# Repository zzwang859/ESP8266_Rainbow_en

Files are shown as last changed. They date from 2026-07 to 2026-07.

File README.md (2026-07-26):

# Rainbow ESP8266

## Features

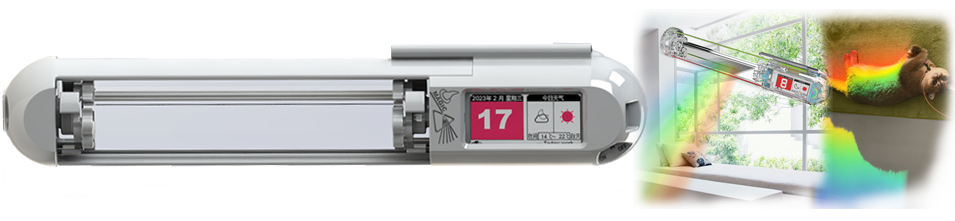
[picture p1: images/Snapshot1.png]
Toy Snapshot


This is an ESP8266-based toy developed with the Arduino environment. It accurately calculates the position of the sun based on geographic location and time, then adjusts the prism's orientation in real time to disperse sunlight into a rainbow projected inside the room, creating a calm and pleasant atmosphere. The program includes a low-power sleep mechanism that allows it to run entirely on solar power. It can also connect to WiFi to retrieve information and display the date, weather, battery level, and configuration status on an e-paper screen.  
[Visit here for more information and a demonstration](https://www.bilibili.com/video/BV1gX4y1D7wM/?vd_source=42ecb46c8304961543d4f286cf99d5a6)

[需要中文版本资料，请点击这里访问中文仓库](https://github.com/zzwang859/ESP8266_Rainbow_zh)

## Directory Structure
```text
.
├── Rainbowv1.0_ESP8266.ino      # Arduino main program entry point
├── Libraries/                   # Archived third-party library packages
│   ├── ArduinoJson.rar
│   ├── ESP8266-Seniverse-master.zip
│   └── NTPClient.rar
├── src/                         # Project source modules
│   ├── config.h                 # Top-level feature configuration macros
│   ├── app_types.h              # Global data structures and state enumerations
│   ├── adc/                     # ADC, battery voltage, and infrared sensor sampling
│   ├── DS1302/                  # DS1302 clock chip driver
│   ├── Epaper/                  # E-paper driver, UI refresh, and image resources
│   ├── moto/                    # Stepper motor control and prism position calibration
│   ├── Sun/                     # Solar position calculation and optimal prism angle search
│   └── wifi_html/               # HTML resources for the WiFi configuration page
├── docments/                    # Project documentation/resources, including program flowcharts and finished product manual
├── Print_Step/                   # Enclosure source files for 3D printing
├── PCB_SCH/                     # Schematic and PCB files
└── images/                      # Finished product photos and actual effect images
```

## Code Deployment Instructions

### Main Program
`Rainbowv1.0_ESP8266.ino` is the main entry point of the Arduino sketch. It contains `setup()`, `loop()`, and the project-level state machine logic. It coordinates the following processes:

- Determine the reset source after power-on/deep-sleep wake-up.
- Restore configuration and operating state from Flash or RTC memory.
- WiFi Station/SoftAP configuration process.
- Time synchronization among NTP, DS1302, and the local perpetual calendar.
- Retrieve weather data and select the city ID.
- Calculate the solar position, sunlight period, and optimal prism angle.
- Schedule stepper motor operations.
- Refresh e-paper display pages.
- Detect low battery and enter low-power sleep.

### Configuration and Global Types
#### `src/config.h`
This is the top-level configuration entry point for the project. The main macros include:  
- `OFFLINE_TEST`: Enables or disables offline/development test mode.
- `DEBUG_INFO_EN`: Enables or disables debug information output.
- `USE_EINK_SCREEN`: Determines whether the e-paper screen is enabled.
- `BAT_LOW_GATE`: Low-battery protection threshold.
- `EINK_MODEL`: E-paper hardware model.
- `EINK_UI_LANGUAGE`: UI language selection, configurable as Chinese or English.

*To customize the startup image, modify the array data of img_config_red &img_config_black in src/epaper/epaper_bmp.h*

### Third-Party Dependencies
The project uses the following Arduino/ESP8266 libraries:
- Libraries included with ESP8266 Arduino Core: `ESP8266WiFi`, `DNSServer`, `ESP8266WebServer`, `SPI`, and `WiFiUdp`.

Third-party library packages are stored in the `Libraries/` directory. Before compilation, make sure these libraries are correctly installed in the Arduino IDE or located in a path that the compiler can search,  
usually: `\Users\name\Documents\Arduino\libraries\ `<br>
- `ArduinoJson`
- `ESP8266_Seniverse`
- `NTPClient`

### Code Maintenance
- Modify top-level feature switches in `src/config.h` first.
- Refer to `src/app_types.h` first for global state structures.
- Hardware pin-related macros are located in the header files of their corresponding modules.

## Schematic and PCB 

The schematic and PCB files are located in `PCB_SCH/` and were designed using EasyEDA. After obtaining them, you will need to manufacture the circuit board yourself. Fortunately, only a small number of inexpensive components are required. All components use 0603 packages, so there are no demanding requirements for soldering equipment or skills. If you are in China, you can have the circuit board manufactured for free by JLCPCB.

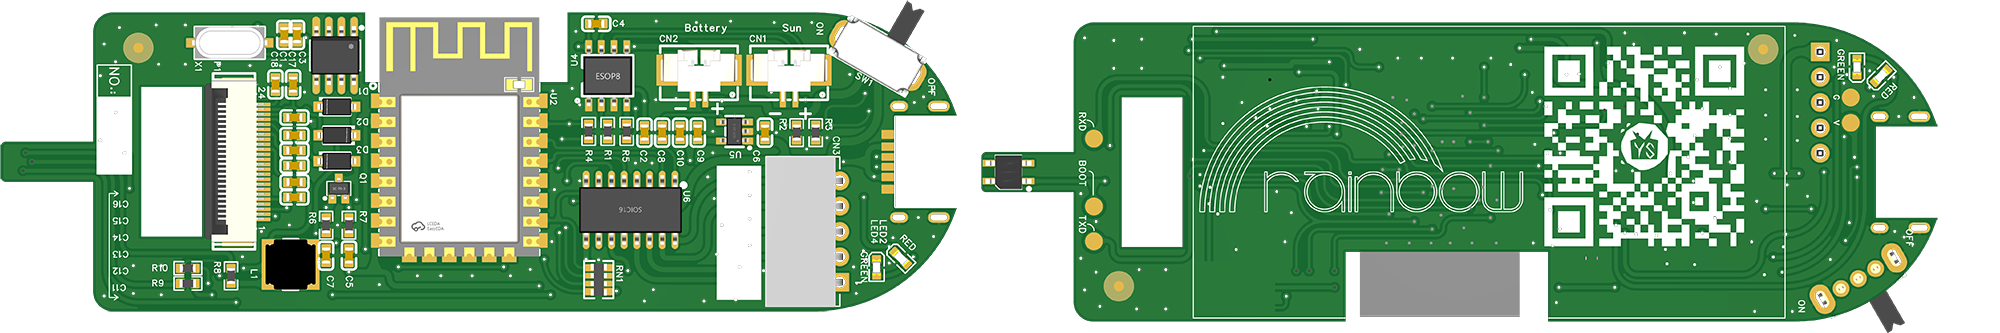
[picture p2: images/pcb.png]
PCBA


## Enclosure and Bill of Materials
The 3D-printable enclosure files are located in the `Print_Step` directory. However, additional materials, such as stepper motors and a solar panel, are required to assemble the complete product. The list is as follows:

|Part Name| Quantity|Unit|Specifications|Notes|
|:---:|:---:|:---:|:---:|:---:|
| Enclosure| 2 |sets | PLA/PETG | 3D Printed |
| PCB| 1 |piece | Fully assembled | DIY |
| Triangular Prism| 1 |piece | 30*30*150mm | Buy |
| Solar Panel| 1|piece |90*30mm 5.5V |Buy|
| Stepper Motor| 2|pieces|28BYJ-48 DC5V | Buy|
| Battery| 2|pieces|102540 1100mAh 1.25mm*2Pin|Buy|
| Bearing| 2|pieces|10mm inner diameter, 22mm outer diameter, 8mm thickness|Buy|
| Brass Standoff| 2|pieces|M3*18mm |Buy|
| E-paper Display|1|piece| 2.13" |Buy|
| M3 Bolt|4 |pieces|M3*10mm |Buy|
| M6 Bolt|2 |pieces|M6*20mm hex socket |Buy|
| M6 Nut|2 |pieces|M6 |Buy|
| M6 Washer|2 |pieces|M6*12*1mm |Buy|

## Finished Product Installation and Setup

#### Mounting on Window Glass
1. First, determine the installation location. This toy requires a vertical window exposed to sunlight. (Horizontal skylights or sloped attic windows are not suitable for installing this toy.)
2. Be sure to clean the glass first to prevent dust or dirt from weakening the adhesive hooks.
3. Attach the adhesive hooks to the product first to ensure the spacing between the hooks is correct.
4. Peel off the backing from the hooks, press the product firmly onto the glass, and ensure that it adheres securely.
5. Remove the product from the hooks, press the hooks firmly against the glass again, and then hang the product back in place.

#### Placing on a Windowsill with Stands
The 3D printing files are located in the `Print_Step` directory, which includes files for a pair of stands that can be printed to support the device.

### Initial Setup

1. Turn on the product's power switch. Use a phone or computer to find and connect to the hotspot named rainbow. The password is 12345678.
2. Then open 192.168.4.1 in a mobile browser. The interface is shown below. Follow the on-screen instructions to enter your home WIFI name and password, the longitude, latitude, and altitude of the installation location, and the window orientation. Then click Connect.<br>

<p align="center">
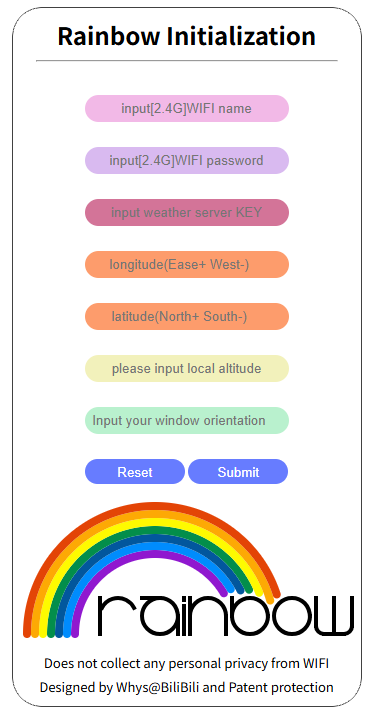
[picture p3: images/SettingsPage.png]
Setting page
  
</p><br>

+ The target WIFI network supports only 2.4 GHz. Connecting to a 5 GHz WIFI hotspot will fail. When configuring with a mobile hotspot, enable the "Maximize Compatibility" option.
+ Verify that the WIFI password is correct. Public WIFI and other hotspots that require additional authentication after connection to access the Internet are not suitable for this toy.
+ For the weather private key, enter "OFF" if you do not use the weather forecast feature. In mainland China, Seniverse is used as the third-party weather information service provider, and users can register a free account with a personal mobile phone number to obtain a private key. If the program is compiled in English, the weather forecast source is Caiyun Weather, which requires a paid subscription.

3. Longitude and latitude data must be entered in decimal format with 5–6 decimal places to provide an accurate geographic location. A more convenient method is to look up the longitude and latitude online at <https://api.map.baidu.com/lbsapi/getpoint/index.html>.<br>
If the data is in degrees-minutes-seconds format (for example, 30°20'56"), convert it to decimal format using the following formula:<br>
$$
\text{Decimal Degrees}
=
\text{Degrees}
+
\frac{\text{Minutes}}{60}
+
\frac{\text{Seconds}}{3600}
$$<br>

4. Altitude can be obtained from a map app or a third-party compass app. The altitude does not need to be precise; an error of about 100 meters has virtually no effect.
- Optional hidden settings can be appended to the altitude value for users with special application requirements. The format and descriptions of the additional settings are shown below. Square brackets around optional parameters are required, and the letters in `UTC/ADJ/NTP/LPR` are case-sensitive.  
    **Required Parameter**<br>
    - Altitude value (required)

    **Optional Parameters**<br>
    - Custom time zone, such as `[UTC+8] 、[UTC-5]` <br>
    - Coordinate system fine-tuning. To compensate for stepper motor gear error, a coordinate system adjustment setting is provided. To make the rainbow smaller and brighter (with a more concentrated beam), adjust slightly in the negative direction, for example: `[ADJ-3.0]`; to make the rainbow larger (more dispersed), adjust slightly in the positive direction, for example: `[ADJ3.0]`. The adjustment is generally within ±6 degrees. Excessive adjustment may prevent a rainbow from forming. <br>
    - Custom NTP time server, for example `[NTPntp1.aliyun.com]` <br>
    
    ```bash
    w32tm /stripchart /computer:ntp.tencent.com  # Method for checking whether an NTP server is available on Windows
    ```
    Some commonly used NTP servers are listed below:
    ```text
    ntp1.aliyun.com
    pool.ntp.org
    ntp.tencent.com
    time.cloud.tencent.com
    time.apple.com
    time.google.com (unavailable in mainland China)
    time.facebook.com (unavailable in mainland China)
    ntp.ix.ru (Moscow)
    ntp.jst.mfeed.ad.jp (Japan)
    ```

    - Custom low-battery warning voltage, for example `[LPR750]`. The valid range is 0–1024. Because the ESP8266 ADC readings are inaccurate, this parameter is provided to prevent the device from incorrectly entering low-battery sleep too early. Setting it to 0 effectively disables low-battery sleep.

5. Window orientation
      The window orientation is a numeric value. True north is 0, and the north-east-south-west-north sequence corresponds to 0–360 degrees, as shown below. Point your phone's built-in compass app toward the window; the displayed reading is the window orientation value.
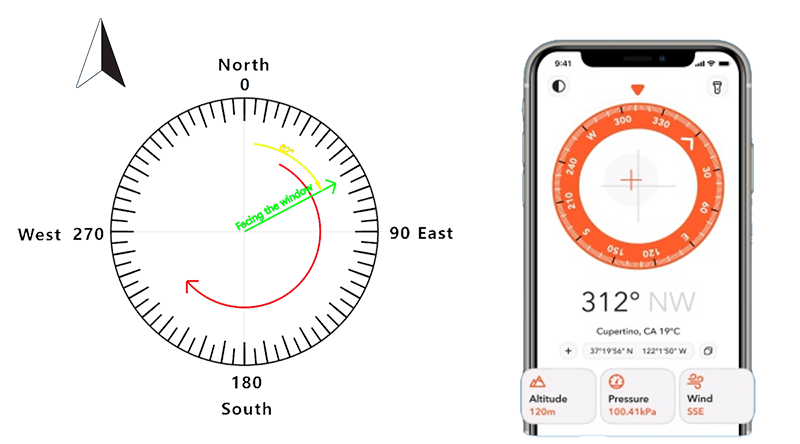
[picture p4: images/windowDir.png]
windowDir
      

*The longitude, latitude, altitude, and window orientation parameters can all be obtained from the phone's built-in "Compass" app. When taking measurements, place the phone flat and point it directly toward the window. (Since iOS 14, Apple's built-in "Compass" app no longer displays longitude, latitude, and altitude information. You can download a third-party "Compass" app from the App Store to obtain this information.)*

#### E-paper Display Information
<p align="center">
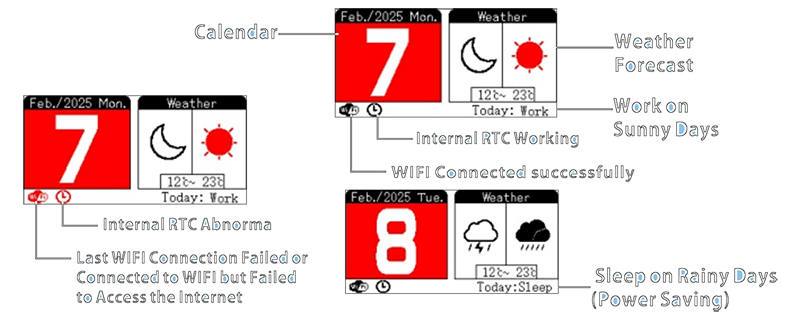
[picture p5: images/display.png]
Display]
  
</p><br>

## ⚠️ Safety Precautions
* Before mounting the product on indoor glass, clean the glass thoroughly to prevent dust or grease from weakening the adhesive bond. 
* Do not manually rotate the product using external force, as this may break the internal gears and damage the product. 
* Do not install the product outdoors on a high-rise building, as an accidental fall could cause personal injury. 
* When the battery is depleted, charge it using a Type-C USB cable. 
* This product is not suitable for use or play by children under 9 years old. 
* This product does not concentrate light and therefore does not present a fire hazard from concentrated sunlight.

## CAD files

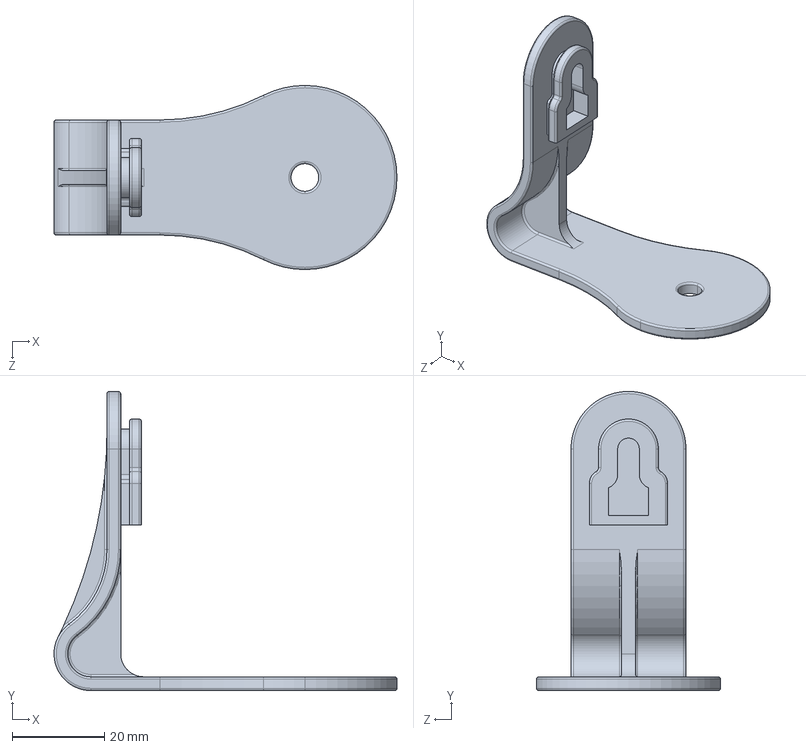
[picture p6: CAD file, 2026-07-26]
Print_Step/bracketx2.STEP
74.5 x 65.0 x 40.0 mm

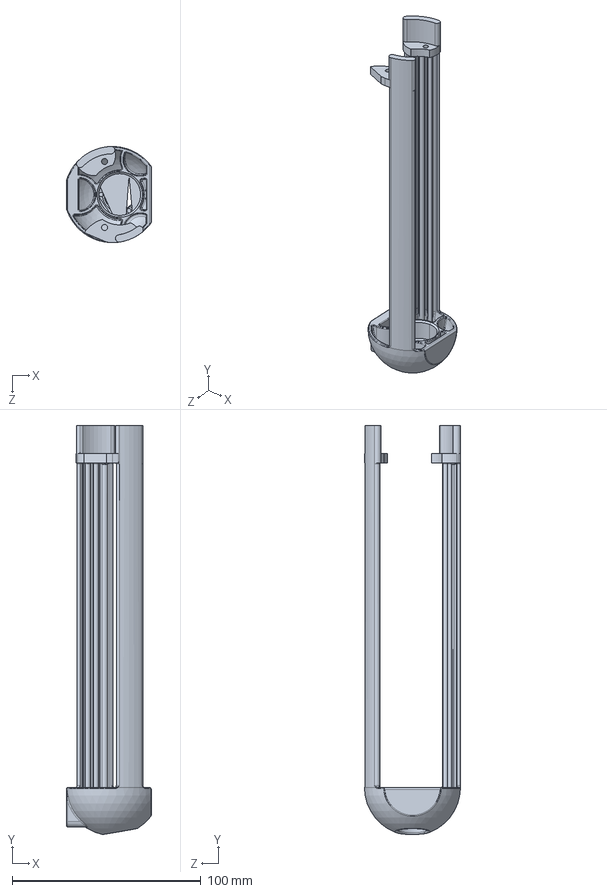
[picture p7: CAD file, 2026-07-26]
Print_Step/L_casing.STEP
44.8 x 216.8 x 51.0 mm

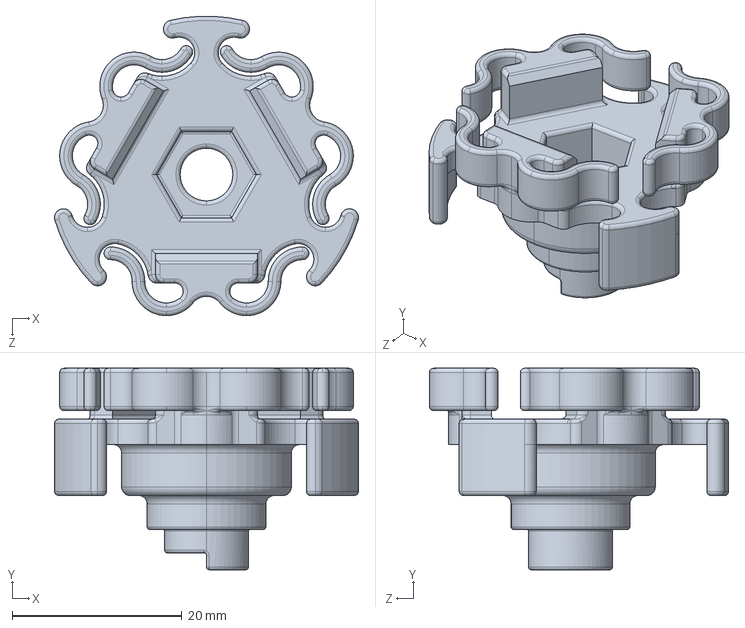
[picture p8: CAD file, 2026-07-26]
Print_Step/Prism_clipR.STEP
35.8 x 23.8 x 35.3 mm

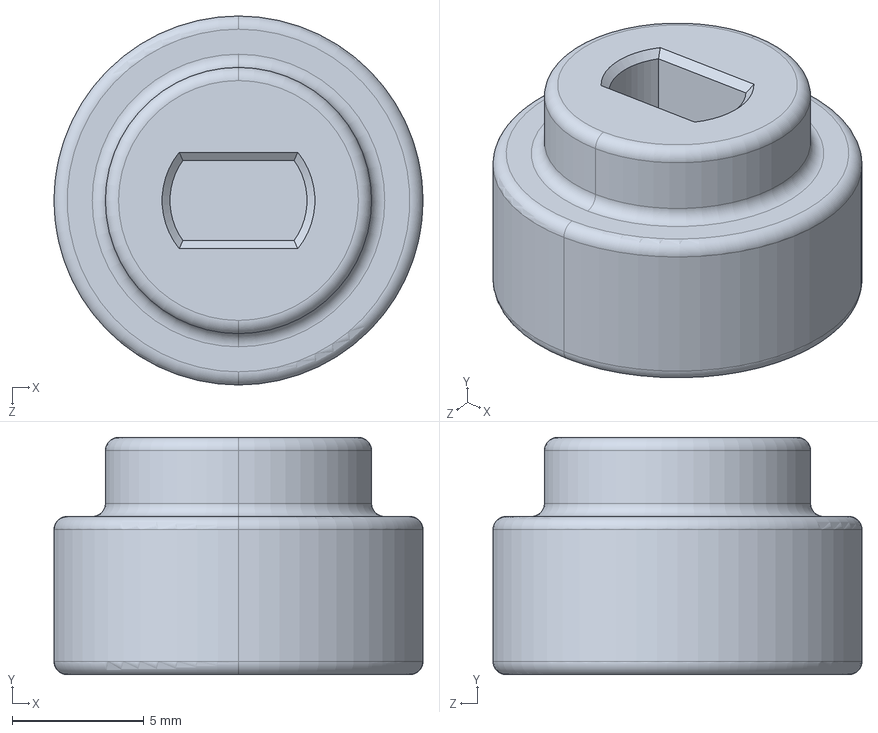
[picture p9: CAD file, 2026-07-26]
Print_Step/Shaft_coupling.STEP
14.0 x 9.00 x 14.0 mm

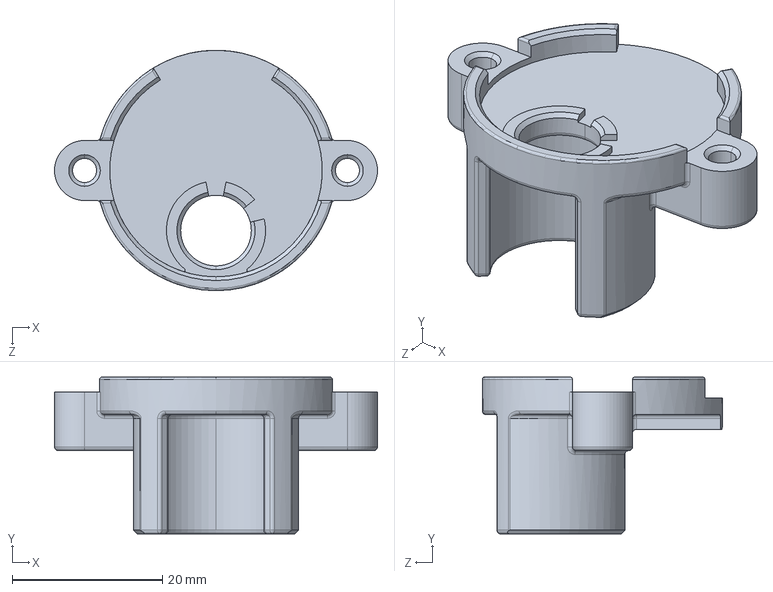
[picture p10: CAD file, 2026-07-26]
Print_Step/motor_base.STEP
43.0 x 20.9 x 32.0 mm

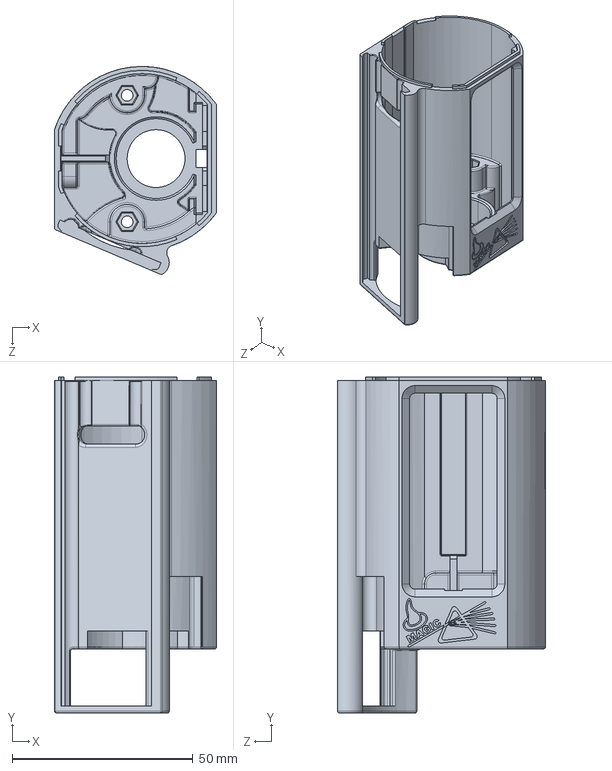
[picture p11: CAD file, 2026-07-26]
Print_Step/R_casing.STEP
44.8 x 93.0 x 57.6 mm

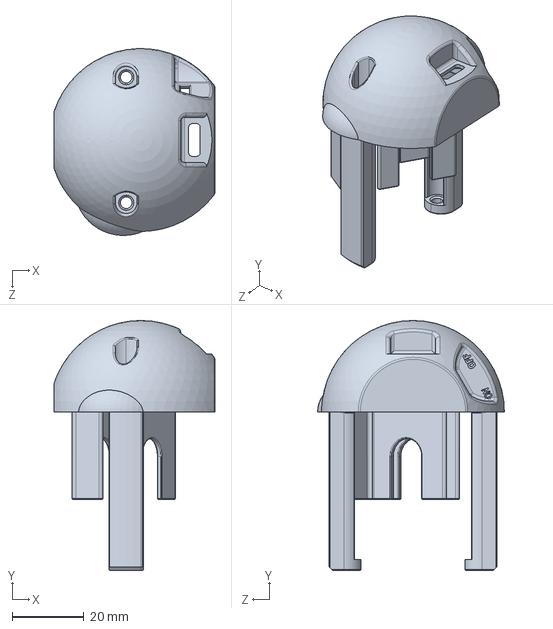
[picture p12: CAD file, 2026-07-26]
Print_Step/end_cover.STEP
44.8 x 69.7 x 52.1 mm

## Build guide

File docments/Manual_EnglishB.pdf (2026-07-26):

2

## installation method

## Initial Setup

## Precautions

When attaching to indoor glass, please clean the glass in advance to avoid dust or oil stains that may cause the adhesive to fail.
Do not manually rotate the product with external force, as this may cause internal gears to break and damage the product.
Do not install the product outdoors at high levels to prevent accidental falls that could cause injury to others.
When the battery is depleted, please use a Type-C USB cable to charge .

This product does not have the function of focusing light and will not cause fire hazards due to sunlight concentration and temperature rise.

This product is not suitable for use or play by children under 9 years old.

Step One: First, determine the installation location. This toy requires a vertical window that can be exposed to sunlight (horizontal skylights or attic windows with an incline are not suitable for installing this toy).

80.356481[UTC-5][ADJ3.0][NTPtime.google.com]

Turn on the power switch of the product, use your phone or computer to find a hotspot named "rainbow" connect to this hotspot, and the password is 12345678

Then, using your phone's browser, open the URL 192.168.4.1 The interface will appear as shown in the image below. Follow the on-screen instructions to fill in your home Wi-Fi's name and password, the latitude, longitude, and altitude of the installation location, and the orientation of the window. Click 'Connect' to proceed.

*If you need to change the parameters, toggle the power switch to turn off and then turn on the device again, and repeat the above steps

Step Three: First, attach the adhesive hooks to the product to ensure that the spacing between the hooks is appropriate.
Step Four: Peel off the adhesive backing from the hooks, then press the product firmly onto the glass to attach it.

Step Two: Be sure to wipe the glass clean first to prevent the adhesive hook from not sticking securely.

Step Five: Remove the product from the hooks, press the hooks further to ensure they are securely attached, and then hang the product back on the hooks.

## ParameterExplanationAnd Tips

1:The target Wi-Fi for connection only supports 2.4G; attempting to connect to a 5G Wi-Fi hotspot will fail. When setting up a mobile hotspot on your phone, please select the 'Best Compatibility' option."

1

Does not collect any personal privacy from WIFI Designed by Whys@BiliBili and Patent protection

input[2.4G]WIFIname

input[2.4G]WIFIpassword

inputweatherserverKEY

longitude(Ease+West-)

latitude(North+South-)

pleaseinputlocalaltitude

Inputyourwindoworientation

Reset | Submit

Rainbow Initialization

LoveHome

z77778888

OFF

-74.252564

40.670951

30

90

Reset | Submit
SetupInterface | FillingExample

2:Verify the Wi-Fi password to ensure it is correct. Public Wi-Fi hotspots that require additional verification to access the internet after connecting are not suitable for this toy. 3：weatherforecastsourceprivatekey
If you do not use the weather forecast feature, it can be set to 'OFF.' Weather is a third-party weather forecast information service provider. Users can register for a free account using their personal phone number to obtain a private key. A registration video tutorial is available; scan the QR code below to access and watch the instructions.
You can also leave it blank, in which case the built-in default private key will be used. However, this may result in weather forecast updates failing due to excessive usage by many users.

4：latitudeandlongitudedata
The format for entering latitude and longitude data should be in decimal format, with 5 to 6 decimal places to provide precise location information. If the data you find is in degrees-minutes-seconds (DMS) format, for example30°20'56".You can convert to decimal format using the formula: decimal format = D + M/60 + S/3600.
A more convenient way is to look up the latitude and longitude online. The QR code for the lookup link is provided below.

Facing the window

62°

GlassProduct

Recycling

CityCleanliness
Responsibility
PreventWater | DoNotStepOn

DoNotStepOn
WeatherAPIKeys | Latitude&LongitudeQuery

5：Altitude
You can check the altitude using a map APP or by installing a third-party compass APP. The altitude value does not need to be precise; an error of around a hundred meters will generally have no significant impact.

4

Hide Additional Parameters
After the altitude value, an Easter egg setting can be appended for users with special application needs to explore. Typically, there is no need to add this. The format and instructions for the additional settings are as follows:

AltitudeValue
(Required）

optionalparameters
CustomTimeZone

optionalparameters
Fine-tunethecoordinatesystem

*Bracketsarenecessaryinoptionalparameters，UTC/ADJ/NTParecase-sensitive

optionalparameters
CustomNTPtimeserver

Toaddressstepmotorgearerrors,asettinghasbeenaddedtoallowfine-tuningofthecoordinate system.
Tomaketherainbowsmallerandbrighter(morefocusedbeam),youcanslightlyadjustthecoordinates inthenegativedirection.Forexample,enter:80.35[ADJ-3.0] Tomaketherainbowarealarger(morespreadout),youcanslightlyadjustthecoordinatesinthe positivedirection.Forexample,enter:80.35[ADJ3.0] Generally,thefine-tuningangleshouldbewithin±6degrees.Over-adjustingmayresultintheinability

6：Window orientation
Window orientation is a pure numeric value, with true north being 0 degrees, and following the sequence of North-East-South-West-North, it corresponds to 0~360 degrees, as shown in the image below. You can use the reading from your phone's built-in compass APP when pointing it towards the window to get the window orientation value.

## 3 on-screen information

Weather
Forecast

Calendar

Workon
SunnyDays

SleeponRainyDays
(PowerSaving)

InternalRTCWorking

WIFI Connected successfully

InternalRTCAbnorma

LastWIFIConnectionFailedor ConnectedtoWIFIbutFailed toAccesstheInternet

CommunicationandQ&A

North

East

South

West

0

90

180

270

The latitude, longitude, altitude, and window orientation parameters can actually be obtained from the built-in 'Compass' app on your phone. When obtaining these values, please hold your phone flat and facing the window directly. (Note: The built-in 'Compass' app on Apple devices no longer displays latitude, longitude, and altitude information starting from iOS 14. You can download a third-party 'Compass' app from the App Store to get this information.)

Rainbow Initialization

180

Does not collect any personal privacy from WIFI Designed by Whys@BiliBili and Patent protection

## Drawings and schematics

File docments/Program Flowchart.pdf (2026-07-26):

## 复位运行

# 全局状

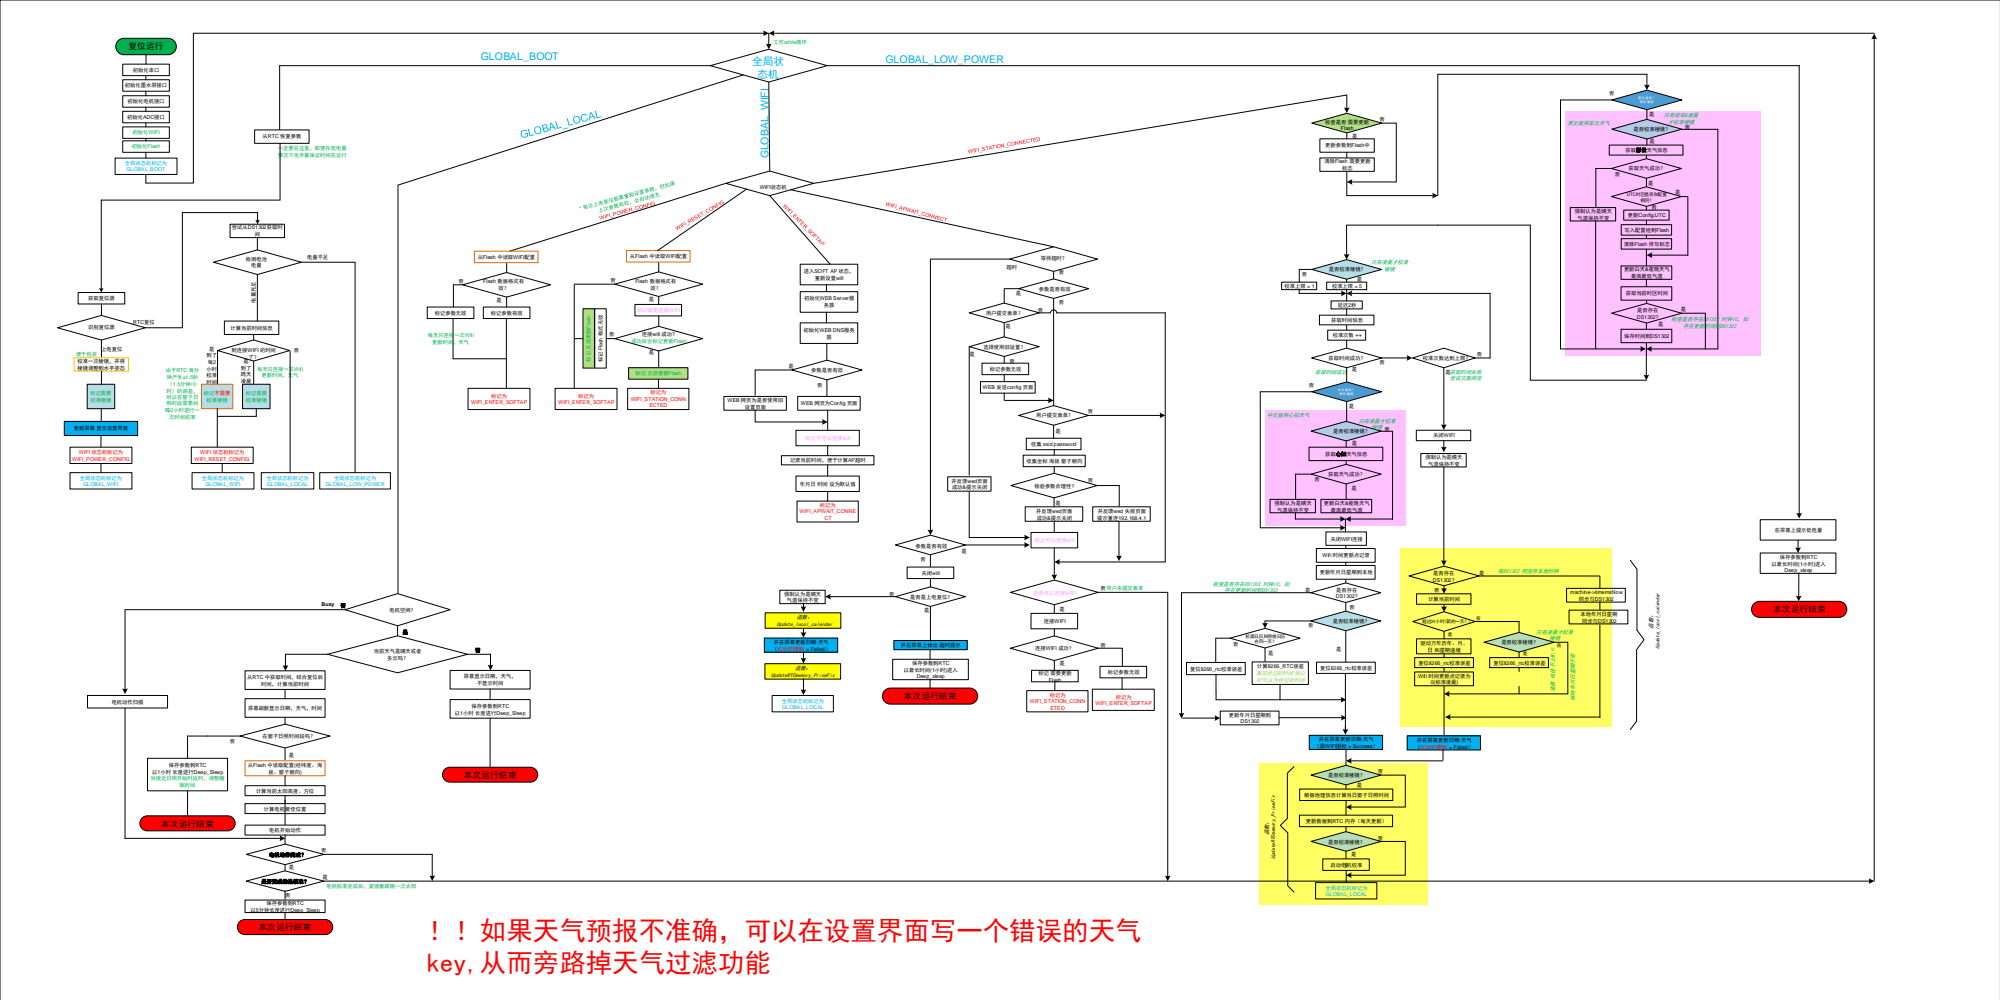
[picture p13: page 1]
初始化串口; 初始化墨水屏接口; 初始化电机接口; 初始化ADC接口; 初始化WIFI; 初始化Flash; 从Flash 中读取WIFI配置; Flash 数据格式有 效？; 连接WIFI; 连接WIFI 成功？; 标记为 WIFI_APWAIT_CONNE CT; 获取复位源; 识别复位源; 上电复位; RTC复位; WIFI状态机; 标记为 WIFI_STATION_CONN ECTED; 标记为 WIFI_ENTER_SOFTAP; 初始化WEB Server服 务器; 标记为 WIFI_STATION_CONN ETED; 标记 无须更新Flash; 标记 需要更新 Flash; 检查是否 需要更新 Flash; 更新参数到Flash中; 获取时间信息; 获取心知天气信息; 标记参数无效; 标记参数有效; 参数是否有效; WIFI 状态机标记为 WIFI_POWER_CONFIG; 全局状态机标记为 GLOBAL_WIFI; 计算当前时间信息; 到连接WIFI 的时间 了？; 每天只连接一次Wifi 更新时间，天气; 全局状态机标记为 GLOBAL_LOCAL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

进入SOFT AP 状态，
重新设置wifi

标记 Flash 格式无效

WEB 发送config 页面

WEB 网页为Config 页面 WEB 网页为是否使用旧

收集 ssid password

收集坐标 海拔 窗子朝向

年月日 时间 设为默认值

从RTC 中获取时间，结合复位后
时间，计算当前时间

屏幕刷新显示日期，天气，时间

从Flash 中读取配置(经纬度、海

更新数据到RTC 内存（每天更新）

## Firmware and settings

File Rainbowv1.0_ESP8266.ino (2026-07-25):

/*------------------------------------------------------------------------------------------------------------------------------------------------------------------------
*                                 Copyright (c) 2018, wangzz <-All rights reserved->
*               
**----------------------------------------------------------------------------------------------------------------------
*   File name:   rainbow.c
*   Brief description: Rainbow tracking clock main program
*
**----------------------------------------------------------------------------------------------------------------------
*   Current version:   V1.0
*   Author/modifier: whys
*   Completion date: November 8, 2022
**----------------------------------------------------------------------------------------------------------------------
*   Replacement version: 
*   Original author: 
*   Completion date: 
------------------------------------------------------------------------------------------------------------------------------------------------------------------------*/
#include <ESP8266WiFi.h>
#include <DNSServer.h>
#include <ESP8266WebServer.h>
#include <SPI.h>
#include <string.h>
#include <WiFiUdp.h>

#include <ArduinoJson.h>
#include <ESP8266_Seniverse.h>
#include <NTPClient.h>  /* NTP clock module */  

#include "src/config.h"                                     /* Project configuration macro                                 */
#include "src/app_types.h"                                  /* Global type and project configuration declarations                     */
#include "src/Sun/sun_position.h"                           /* Sun position calculation module declaration section                   */
#include "src/Sun/find_angle.h"                             /* Best pose finding algorithm declaration section                   */
#include "src/moto/moto.h"                                  /* Stepper motor driver declaration section                        */
#include "src/adc/adc.h"                                    /* ADC voltage acquisition statement section                       */
#include "src/DS1302/DS1302.h"                              /* DS1302 clock chip driver declaration part                */

/*------------------------------------------------------------------------------------------------------------------------------------------------------------------------
 * Statement related to WiFi configuration
------------------------------------------------------------------------------------------------------------------------------------------------------------------------*/
#define CONFIG_DATA_BASEADDR         0x100000          /* Store initial installation parameters at 1M location */
#define CONFIG_DATA_SECTOR           256               /* 1M position corresponds to 256 sectors  */
#define TIME_CORRECT_PERIOD_MS       (1200000)         /* Used during the sunshine period. From the time when the window has sunshine, how often should the time be calibrated? It needs to be more than 5 minutes. The unit is ms. This item is invalid when using DS1302.*/        
#define UPDATE_TIME_PRISM            (86400000+6e5)    /* Update time and prism time are 24 hours + 10 minutes (the router may automatically reset at midnight) (the prism must be calibrated at night to avoid sunlight interference)*/
#define WIFI_APWAIT_TIMEOUT_POWERON  (10*6e4)          /* During initial installation, the AP status waiting timeout is 10 minutes.    */
#define WIFI_APWAIT_TIMEOUT_WAKEUP   (3*1e3)           /* When waking up from work, the AP status wait timeout should not be too long to avoid power consumption.  */
#define LONG_SLEEP_TIME              (60*6e4)          /* Long sleep duration */

 
const char* AP_NAME = "rainbow";       /* softAP hotspot name  */
const char* AP_PWD = "12345678";       /* softAP hotspot password  */

const byte DNS_PORT = 53;             /* DNS port number           */
IPAddress apIP(192, 168, 4, 1);       /* esp8266-AP-IP address   */
DNSServer dnsServer;                  /* Create dnsServer instance  */
ESP8266WebServer server(80);          /* Create WebServer instance  */

WiFiUDP ntpUDP;
NTPClient timeClient(ntpUDP, "ntp.tencent.com",60*60*8, 30*60*1000);
const char DefaultNTP[] = "ntp.tencent.com";

#if USE_EINK_SCREEN 
#include "src/Epaper/epaper.h"
#endif

/*------------------------------------------------------------------------------------------------------------------------------------------------------------------------
 * global variables
------------------------------------------------------------------------------------------------------------------------------------------------------------------------*/
#if(EINK_UI_LANGUAGE == EINK_LANGUAGE_CHINESE)
Forecast forecast; /*  Create a Forecast object to obtain informed weather information*/
#endif

#if(EINK_UI_LANGUAGE == EINK_LANGUAGE_ENGLISH)
Caiyun forecast; /*  Create a Forecast object to obtain Caiyun weather information*/
#endif

/*--------------- state machine -------------------------------------*/
/* Global configuration updated during initial installation*/
_FIXED_CONFIG Config
{
    {0},                /* Save wifi account      */
    {0},                /* Save wifi password      */
    0,                  /* save longitude           */
    0,                  /* save latitude           */
    0,                  /* save altitude           */
    0,                  /* Save window orientation       */
    0,                  /* Fine-tuning the reflective column position of the hardware structure */ 
    0,                  /* Set time zone             */
    {0},                /* Set default NTP server    */
    0,                  /* Is there an old configuration?     */
    0,                  /* Is it possible to connect to WiFi?   */
    0,                  /* Whether it is necessary to write to Flash  */
    0,                  /* Low battery reminder voltage      */
}; 

/* Global status data definition updated daily */
 _GLOBAL_MACHINE Machine ={
    0 ,               /* global state machine                 */
    0 ,               /* WiFi transaction state machine             */
    0 ,               /* Whether to calibrate prism, lighting time, weather */
    0 ,               /* Time to enter AP mode          */
    {0,0,0,0,},       /* Today's weather                  */
    0 ,               /* Window sunshine start time           */
    0 ,               /* Window sunshine end time           */
    0 ,               /* year                        */
    0 ,               /* month                        */
    0 ,               /* day                        */
    0 ,               /* week                      */
    0 ,               /* The best posture of prism in the last 5 minutes        */
    0 ,               /* Last sleep time               */
    0 ,               /* Current time in milliseconds        */
    0 ,               /* Timestamp when updating time when connected to wifi  */   
    0 ,               /* RTC frequency offset fine-tuning 1.0 positive and negative adjustment  */ 
    0 ,               /* Record the reset source of this startup         */ 
    0 ,               /* Reserve                      */ 
    0 ,               /* Reserve                      */ 
    0 ,               /* Reserve                      */ 
};    

#if OFFLINE_TEST
/*---------------  Serial console related, offline mode debugging use -------------------------------------*/
uint8_t guc_UART0cmd = 'Z';

uint32_t cnt = 0;                   /* Debugging use                  */
uint32_t user_triger = 0;           /* For debugging use, force the trigger to move.  */
uint32_t prestart = 0;              /* Debugging use, last motor action time  */

uint16_t  win_shine_start = 494;    /* Debugging use, lighting start time     */
uint16_t angle_list[] = {           /* For debugging use, look up the table to calculate the position.     */
 200, 196, 192, 190, 187, 184, 182, 180, 177, 175, 173, 171, 169, 167,
 165, 163, 161, 160, 158, 156, 155, 153, 152, 150, 149, 148, 147, 146, 145, 144,
 143, 142, 141, 140, 140, 139, 138, 138, 137, 137, 137, 136, 136, 136, 136, 136,
 136, 136, 136, 136, 137, 137, 137, 138, 138, 139, 139, 140, 140, 141, 141, 142,
 143, 143, 144, 145, 145, 146, 147, 147, 148, 149, 150, 150, 151, 152, 153, 154,
 154, 155, 156, 157, 158, 158, 159, 160, 161, 162, 162, 163, 164, 165, 166, 167,
 168, 169, 169, 170, 171, 172, 173, 174, 175, 176, 178, 179, 180, 181, 182, 184,
 185, 187, 188,};
 #endif

#if(EINK_UI_LANGUAGE == EINK_LANGUAGE_CHINESE)
const char my_weather_key[] = "SUfADtTVXqqdqaJ8J";          /* Personal private key to know the weather, backup when necessary */
#endif

#if(EINK_UI_LANGUAGE == EINK_LANGUAGE_ENGLISH)
const char my_weather_key[] = "8OyNmkKGoKRYbGfk";           /* Personal Caiyun Weather private key, backup when necessary */
#endif

#include "src/wifi_html/wifi_html.h"                        /* Web server source code statement */


/**********************************************************************************************************************
*   Function name: Offline_Test (used for debugging)
*   Function description: Drive the motor to rotate based on local time, without using WiFi and without going to sleep.
*   Parameter list: None
*   Hardware output: None
*   Return result: None
*   History: Author/Modifier Date Remarks
*              whys 2018.6.29 Original creation version V1.0
*
**********************************************************************************************************************/
#if OFFLINE_TEST
void Offline_Test(_GLOBAL_MACHINE * machine, _MOTO_CTRL * moto )
{
  uint16_t index = 0;
  uint32_t timeCurrent = 0;
  uint16_t sum_minutes = 0;

  timeCurrent = machine->timemsNow + millis();             /* Calculate total time in milliseconds                 */
  sum_minutes = timeCurrent/60e3;                         /* Convert to minutes                     */

  if ( sum_minutes > win_shine_start) {                   /* Greater than the lighting start time                               */
      if((sum_minutes-win_shine_start) % 5 == 0 || user_triger !=0){        /* Trigger once every 5 minutes or manually trigger   */
        user_triger =0;      
        if(millis() - prestart > 61e3) {                  /* The next trigger will be performed 61 seconds after the last trigger to prevent repeated triggers. */
          prestart = millis() ;                           /* Note the time of this trigger                             */

          index = (uint16_t) ((sum_minutes-win_shine_start)/5);
          if(index < sizeof(angle_list)/2-1) {

            /* Deflecting more downward can ensure that total reflection will not occur in the next 5 minutes. */            
            if(angle_list[index +1] > angle_list[index]) {
              moto->goToAbsLocation((float) angle_list[index+1]);           /* Start motor action      */
            } else {
              moto->goToAbsLocation((float) angle_list[index]);             /* Start motor action       */              
            }

            /* Serial port displays time and action angle */
#if DEBUG_INFO_EN
            Serial.printf("time: %d:%02d moto angle: %d\r\n",  (uint16_t)((timeCurrent % 86400000) / 3600000), (uint16_t)((timeCurrent % 3600000 ) / 60000),angle_list[index]); 
#endif  
          }           
        }   
      }      
  }   
}
#endif


/*------------------------------------------------------------------------------------------------------------------------------------------------------------------------
 * Code: state machine
------------------------------------------------------------------------------------------------------------------------------------------------------------------------*/
/**********************************************************************************************************************
*   Function name: local_calendar
*   Function description: Local perpetual calendar, when obtaining time from the Internet fails, use the local perpetual calendar
*   Parameter list: machine global variable top-level state machine
*   Hardware output: None
*   Return result: None
*   History: Author/Modifier Date Remarks
*              whys 2018.6.29 Original creation version V1.0
*
**********************************************************************************************************************/
void local_calendar( _GLOBAL_MACHINE * machine)
{
  uint8_t month_list1[12] = {31,28,31,30,31,30,31,31,30,31,30,31};

  /* Determine leap year*/
  if(machine->month == 2){
    if(((machine->year%4 == 0) && (machine->year%100 != 0))|| (machine->year%400 == 0) ){
       month_list1[1] = 29; 
    }
  }  

  machine->day += 1;
  if(machine->day > month_list1[machine->month -1]){ /* If it is greater than the number of days in the current month */
    machine->day = 1;
    machine->month +=1;

    if(machine->month > 12) {
        machine->month = 1;
        machine->year +=1;
    }
  }
}

/**********************************************************************************************************************
*   Function name: Press_Data_to_RTCmemory
*   Function description: Write time, date, weather and other information from RTC memory
*   Parameter list: Global_State global variable top-level state
*              moto: Motor state machine
*               sel: RTC_UPDATE_WiFi updates RTC memory after synchronizing data from WiFi
*                    RTC_UPDATE_SLEEP Update RTC memory before sleeping
*   Hardware output: None
*   Return result: None
*   History: Author/Modifier Date Remarks
*              whys 2018.6.29 Original creation version V1.0
*
**********************************************************************************************************************/
static void Press_Data_to_RTCmemory(_GLOBAL_MACHINE * machine, _MOTO_CTRL *moto, uint8_t sel)
{  
  /* Date Weather Illumination Time Only updated after Wifi is synchronized from the network */   
  if(sel == RTC_UPDATE_WIFI) { 
    /* The RTC storage area supports a total of 128 4-byte data (that is, a total of 512 bytes of content can be stored), and the address offset value is 0 ~ 127*/
    ESP.rtcUserMemoryWrite(0, (uint32_t*)&machine->weatherToday, sizeof(machine->weatherToday));  /* Today's weather                  */
    ESP.rtcUserMemoryWrite(1, (uint32_t*)&machine->shine_start,  sizeof(machine->shine_start));   /* Window sunshine start time           */
    ESP.rtcUserMemoryWrite(2, (uint32_t*)&machine->shine_stop,   sizeof(machine->shine_stop));    /* Window sunshine end time           */
    ESP.rtcUserMemoryWrite(3, (uint32_t*)&machine->year,         sizeof(machine->year));          /* year                        */
    ESP.rtcUserMemoryWrite(4, (uint32_t*)&machine->month ,       sizeof(machine->month));         /* month                        */
    ESP.rtcUserMemoryWrite(5, (uint32_t*)&machine->day,          sizeof(machine->day));           /* day                        */
    ESP.rtcUserMemoryWrite(6, (uint32_t*)&machine->weekday,      sizeof(machine->weekday));       /* week                      */    
    machine->timemsNow = machine->timemsNow;                                                      /* Calculate Boot time            */

    ESP.rtcUserMemoryWrite(12, (uint32_t*)&machine->wifilog,      sizeof(machine->wifilog));       /* Update wifi timestamp */
    ESP.rtcUserMemoryWrite(13, (uint32_t*)&machine->rtc_adj,      sizeof(machine->rtc_adj));       /* Update rtc adjustment value   */
    /* Update RTC calibration variables */

  /* Sleep information is only updated when entering sleep mode  */ 
  } else {
    ESP.rtcUserMemoryWrite(7, (uint32_t*)&machine->best_rotate, sizeof(machine->best_rotate));    /* best angle                  */ 
    ESP.rtcUserMemoryWrite(8, (uint32_t*)&machine->sleepedTime, sizeof(machine->sleepedTime));    /* time to sleep             */
    machine->timemsNow += millis();                                                               /* Save time before sleep           */
    /* Save motor status */

    ESP.rtcUserMemoryWrite(10, (uint32_t*)&moto->beat, sizeof(moto->beat));                       /* Save current motor position           */
    ESP.rtcUserMemoryWrite(11, (uint32_t*)&moto->standLoca, sizeof(moto->standLoca));             /* Save current motor beat           */  
                                                  
  }
  /* Update time every time  */ 
  ESP.rtcUserMemoryWrite(9, (uint32_t*)&machine->timemsNow, sizeof(machine->timemsNow));          /* Save current time information           */


}

/**********************************************************************************************************************
*   Function name: Resume_Data_from_RTCmemory
*   Function description: After waking up from deep sleep, restore time, date, weather and other information from RTC memory  
*   Parameter list: Global_State global variable top-level state
*              moto: Motor state machine
*   Hardware output: None
*   Return result: None
*   History: Author/Modifier Date Remarks
*              whys 2018.6.29 Original creation version V1.0
*
**********************************************************************************************************************/
static void Resume_Data_from_RTCmemory(_GLOBAL_MACHINE * machine, _MOTO_CTRL *moto)
{
    /* Because RAM data is lost after deep sleep, all data must be updated */   
    ESP.rtcUserMemoryRead(0, (uint32_t*)&machine->weatherToday, sizeof(machine->weatherToday));  /* Today's weather                  */
    ESP.rtcUserMemoryRead(1, (uint32_t*)&machine->shine_start,  sizeof(machine->shine_start));   /* Window sunshine start time           */
    ESP.rtcUserMemoryRead(2, (uint32_t*)&machine->shine_stop,   sizeof(machine->shine_stop));    /* Window sunshine end time           */
    ESP.rtcUserMemoryRead(3, (uint32_t*)&machine->year,         sizeof(machine->year));          /* year                        */
    ESP.rtcUserMemoryRead(4, (uint32_t*)&machine->month ,       sizeof(machine->month));         /* month                        */
    ESP.rtcUserMemoryRead(5, (uint32_t*)&machine->day,          sizeof(machine->day));           /* day                        */
    ESP.rtcUserMemoryRead(6, (uint32_t*)&machine->weekday,      sizeof(machine->weekday));       /* week                      */ 
    ESP.rtcUserMemoryRead(7, (uint32_t*)&machine->best_rotate,  sizeof(machine->best_rotate));   /* best angle                   */
    ESP.rtcUserMemoryRead(8, (uint32_t*)&machine->sleepedTime,  sizeof(machine->sleepedTime));   /* last sleep time             */
    ESP.rtcUserMemoryRead(9, (uint32_t*)&machine->timemsNow,    sizeof(machine->timemsNow));     /* The time of last sleep           */

    machine->timemsNow += machine->sleepedTime  ;                                           /* Boot time = last sleep point + sleep duration */

    /* Restore motor status */
    ESP.rtcUserMemoryRead(10, (uint32_t*)&moto->beat,            sizeof(moto->beat));             /* Restore current motor position           */
    ESP.rtcUserMemoryRead(11, (uint32_t*)&moto->standLoca,       sizeof(moto->standLoca));        /* Restore current motor beat           */   
    moto->beat%=8;                                                                                /* Prevent array subscripts from going out of bounds           */                                                     
    moto->standLoca %=4096;                                                                       /* Constraint standard numerical range           */

    ESP.rtcUserMemoryRead(12, (uint32_t*)&machine->wifilog,      sizeof(machine->wifilog));       /* Update wifi timestamp */
    ESP.rtcUserMemoryRead(13, (uint32_t*)&machine->rtc_adj,      sizeof(machine->rtc_adj));       /* Update rtc adjustment value   */
}

/**********************************************************************************************************************
*   Function name: Enter_DeepSleep
*   Function description: Clean IO power consumption status, save runtime parameters, and then enter deep sleep
*   Parameter list: Global_State global variable top-level state
*             sleepsms: the length of time to sleep in ms
*   Hardware output: None
*   Return result: None
*   History: Author/Modifier Date Remarks
*              whys 2018.6.29 Original creation version V1.0
*
**********************************************************************************************************************/
static void Enter_DeepSleep( _GLOBAL_MACHINE * machine, uint32_t sleepms)
{
    /************* Adjust IO port status to save power *********************/
    /* Turn off all windings to prevent heating */
    digitalWrite(MOTO_A, LOW);
    digitalWrite(MOTO_B, LOW);
    digitalWrite(MOTO_C, LOW);
    digitalWrite(MOTO_D, LOW);  

    digitalWrite(ADC_CTRL, LOW);  /* ADC power path closed   */
    digitalWrite(IR_DRIVE, HIGH); /* Infrared diode goes out    */
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
void loop() {
#if OFFLINE_TEST
  //prcess_global_local((_GLOBAL_MACHINE *) &Machine, (_FIXED_CONFIG *) &Config);
  UART_Console();                                                                        /* Serial console debugging use        */
#else
  global_state_machine( (_GLOBAL_MACHINE *) &Machine, (_FIXED_CONFIG *) &Config);
#endif
}

/*------------------------------------------------------------------------------------------------------------------------------------------------------------------------
 * END of file
------------------------------------------------------------------------------------------------------------------------------------------------------------------------*/

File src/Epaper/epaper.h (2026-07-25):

#ifndef __EPAPER_H
#define __EPAPER_H 
#include <Arduino.h>
#include "stdlib.h"	
#include "../app_types.h"

/**********************************************************************************************************************
*  Hardware GPIO corresponding
**********************************************************************************************************************/
// //-----------------EINKPort definition---------------- 
// #define EINK_SCL_Clr() GPIO_ResetBit(GPIOA, GPIO_PIN15)//SCL
// #define EINK_SCL_Set() GPIO_SetBit( GPIOA, GPIO_PIN15)

// #define EINK_SDA_Clr() GPIO_ResetBit(GPIOA, GPIO_PIN14)//SDA
// #define EINK_SDA_Set() GPIO_SetBit( GPIOA, GPIO_PIN14)

// #define EINK_RES_Clr() GPIO_ResetBit(GPIOA, GPIO_PIN13)//RES
// #define EINK_RES_Set() GPIO_SetBit( GPIOA, GPIO_PIN13)

// #define EINK_DC_Clr()  GPIO_ResetBit(GPIOA, GPIO_PIN12)//DC
// #define EINK_DC_Set()  GPIO_SetBit( GPIOA, GPIO_PIN12)

// #define EINK_CS_Clr()  GPIO_ResetBit(GPIOA, GPIO_PIN9)//CS
// #define EINK_CS_Set()  GPIO_SetBit( GPIOA, GPIO_PIN9)

// #define EINK_BUSY()    GPIO_ReadInputbit(GPIOA,GPIO_PIN7)

/* Display related GPIO pins */
#define EINK_RST  (0)  /* Reuse */ 
#define EINK_DC   (1) 
#define EINK_CS   (2) 
#define EINK_BSY  (3) 
#define EINK_DAT  (13)  /* Reuse */ 
#define EINK_CLK  (14)  /* Reuse */ 

#define EINK_SCL_Clr() digitalWrite(EINK_CLK, LOW)//SCL
#define EINK_SCL_Set() digitalWrite(EINK_CLK, HIGH)

#define EINK_SDA_Clr() digitalWrite(EINK_DAT, LOW)//SDA
#define EINK_SDA_Set() digitalWrite(EINK_DAT, HIGH)

#define EINK_RES_Clr() digitalWrite(EINK_RST, LOW)//RES
#define EINK_RES_Set() digitalWrite(EINK_RST, HIGH)

#define EINK_DC_Clr()  digitalWrite(EINK_DC,  LOW)//DC
#define EINK_DC_Set()  digitalWrite(EINK_DC,  HIGH)

#define EINK_CS_Clr()  digitalWrite(EINK_CS,  LOW)//CS
#define EINK_CS_Set()  digitalWrite(EINK_CS,  HIGH)

#define EINK_BUSY()    digitalRead(EINK_BSY)


/**********************************************************************************************************************
*  Function parameter macro declaration
**********************************************************************************************************************/
/* Ink screen model list */
// #define EINK_MODEL_SSD1680_250X122    0     /* Zhongjingyuan   */
// #define EINK_MODEL_UD8251_250X122     1     /* Xinchuangtianyuan */
// #define EINK_MODEL_SSD1680_212X104    2     /* Xianyu Procurement */
// #define EINK_MODEL_PERVASIVE_212X104  3     /* Longting New Technology */

/* Ink screen interface language list */
// #define EINK_LANGUAGE_CHINESE  0
// #define EINK_LANGUAGE_ENGLISH  1

/****** Macro definitions related to the Ink Screen hardware platform********************************************************/
// #define EINK_MODEL          EINK_MODEL_SSD1680_212X104 

/****** Ink screen display interface language*************************************************************/
// #define EINK_UI_LANGUAGE  EINK_LANGUAGE_CHINESE

                              
/****** SSD1680 Zhongjingyuan ****************************************************/
#if EINK_MODEL== EINK_MODEL_SSD1680_250X122
  #define EINK_WIDTH         250
  #define EINK_HEIGH         122
  #define EINK_HEIGH_BYTE    16   /* Align height by bytes */

  #define EINK_BUSY_STATE    0x1  /* The value of the BUSY pin when in the BUSY state  */

  #define EINK_LAYER_BW     0x24  /* Layer 1 Data Transfer Command */
  #define EINK_LAYER_RE     0x26  /* Layer 2 Data Transfer Commands */

  #define BW_COLOR_BLACE    0x0   /* The black layer is ink text 0= black*/
  #define BW_COLOR_WHITE    0xff  /* The black layer is the ink text 1= white*/
  #define RE_COLOR_RED      0xff  /* The red layer is Yangwen 1= red*/
  #define RE_COLOR_EMPTY    0x0   /* The red layer is Yangwen 0= white*/
#endif

/****** UC8251 Xinchuangtianyuan **************************************************/
#if EINK_MODEL== EINK_MODEL_UD8251_250X122
  #define EINK_WIDTH         250
  #define EINK_HEIGH         122
  #define EINK_HEIGH_BYTE    16   /* Align height by bytes */  

  #define EINK_BUSY_STATE    0x0 /* The value of the BUSY pin when in the BUSY state  */

  #define EINK_LAYER_BW     0x10  /* Layer 1 Data Transfer Command */
  #define EINK_LAYER_RE     0x13  /* Layer 2 Data Transfer Commands */

  #define BW_COLOR_BLACE    0x0   /* The black layer is ink text 0= black*/
  #define BW_COLOR_WHITE    0xff  /* The black layer is the ink text 1= white*/
  #define RE_COLOR_RED      0xff  /* The red layer is Yangwen 1= red*/
  #define RE_COLOR_EMPTY    0x0   /* The red layer is Yangwen 0= white*/
#endif

/****** SSD1680 Xianyu Procurement ****************************************************/
#if EINK_MODEL== EINK_MODEL_SSD1680_212X104
  #define EINK_WIDTH         212
  #define EINK_HEIGH         104
  #define EINK_HEIGH_BYTE    13   /* Align height by bytes */

  #define EINK_BUSY_STATE    0x1  /* The value of the BUSY pin when in the BUSY state  */

  #define EINK_LAYER_BW     0x24  /* Layer 1 Data Transfer Command */
  #define EINK_LAYER_RE     0x26  /* Layer 2 Data Transfer Commands */

  #define BW_COLOR_BLACE    0x0   /* The black layer is ink text 0= black*/
  #define BW_COLOR_WHITE    0xff  /* The black layer is the ink text 1= white*/
  #define RE_COLOR_RED      0xff  /* The red layer is Yangwen 1= red*/
  #define RE_COLOR_EMPTY    0x0   /* The red layer is Yangwen 0= white*/
#endif

/****** UC8251 Longting New Technology **************************************************/
#if EINK_MODEL== EINK_MODEL_PERVASIVE_212X104
  #define EINK_WIDTH        212
  #define EINK_HEIGH        104
  #define EINK_HEIGH_BYTE    13   /* Align height by bytes */

  #define EINK_BUSY_STATE    0x0 /* The value of the BUSY pin when in the BUSY state  */

  #define EINK_LAYER_BW     0x10  /* Layer 1 Data Transfer Command */
  #define EINK_LAYER_RE     0x13  /* Layer 2 Data Transfer Commands */

  #define BW_COLOR_BLACE    0xff   /* The black layer is ink text 0= black*/
  #define BW_COLOR_WHITE    0x0  /* The black layer is the ink text 1= white*/
  #define RE_COLOR_RED      0xff  /* The red layer is Yangwen 1= red*/
  #define RE_COLOR_EMPTY    0x0   /* The red layer is Yangwen 0= white*/
#endif


/**** Software pictures display related macro definitions ****************************************************************/
#define EINK_STAGE_INIT     0x0   /* initialization phase */
#define EINK_STAGE_DISP     0x1   /* display stage   */

#define EINK_BWPART_REPLACE 0x00
#define EINK_BWPART_CLEAN   0x01
#define EINK_BWPART_SET     0x02

#define EINK_REPART_REPLACE 0x10
#define EINK_REPART_CLEAN   0x11
#define EINK_REPART_SET     0x12

#define ICON_BW_LAYER       0x00
#define ICON_RE_LAYER       0x10

#define WIFI_CONNECT_FAILED  0   /* WiFi connection failed */
#define WIFI_CONNECT_SUCCESS 1   /* WiFi connection successful */
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

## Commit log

2026-07-26 add readme file
    [bracketx2.STL]
2026-07-26 replace 3D STL file with Setp fils
    [L_casing.STEP, Prism_clipL.STEP, Prism_clipR.STEP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]
